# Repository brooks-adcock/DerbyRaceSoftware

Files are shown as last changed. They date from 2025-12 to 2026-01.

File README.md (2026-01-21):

# Pinewood Derby Race Software

Complete race management system for Pinewood Derby events, featuring automatic timing hardware and a modern web UI.

## Architecture Overview

```
┌─────────────────────────────────────────────────────────────────────┐
│                           WEB UI (Next.js)                          │
│              Race management, registration, results display         │
│                         http://localhost:3000                       │
└─────────────────────────────────────────────────────────────────────┘
                                    │
                                    │ HTTP + WebSocket
                                    ▼
┌─────────────────────────────────────────────────────────────────────┐
│                    TRACK CONTROLLER (Raspberry Pi)                  │
│           FastAPI server for gate control + finish sensors          │
│                   http://track-controller.local:8000                │
└─────────────────────────────────────────────────────────────────────┘
                                    │
                         GPIO / I2C │
                                    ▼
┌─────────────────────────────────────────────────────────────────────┐
│                          PHYSICAL HARDWARE                          │
│         Gate servo (PCA9685) + IR break-beam sensors (x4)           │
└─────────────────────────────────────────────────────────────────────┘
```

## Components

| Directory | Description |
|---|---|
| `ui_web/` | Next.js web application for race management |
| `pi/` | Raspberry Pi track controller (FastAPI + GPIO) |
| `mechanical/` | 3D printable parts (STL files) for track hardware |
| `notes/` | Development notes and troubleshooting logs |

---

## Quick Start

### 1. Development Environment (UI Only)

```bash
# Start the web UI (mock hardware mode)
./dev_start.sh

# View logs
./dev_tail.sh

# Stop services
./dev_stop.sh
```

Access at http://localhost:3000

### 2. Full System with Pi Hardware

See [pi/README.md](pi/README.md) for hardware setup instructions.

---

## Development Scripts

| Script | Description |
|---|---|
| `./dev_start.sh` | Start Docker services in background |
| `./dev_stop.sh` | Stop all Docker services |
| `./dev_build.sh` | Rebuild containers (fresh install) |
| `./dev_build.sh ui_web` | Rebuild specific service |
| `./dev_tail.sh` | Follow Docker logs |

---

## Web UI Pages

| Route | Purpose |
|---|---|
| `/` | Home / dashboard |
| `/register` | Car registration form |
| `/heats` | Heat management and race control |
| `/results` | Results leaderboard |
| `/public` | Spectator display (large screen) |
| `/admin` | System administration |
| `/health` | Hardware connection status |

---

## Track Controller API

The Raspberry Pi exposes a REST + WebSocket API:

| Endpoint | Method | Description |
|---|---|---|
| `/health` | GET | Health check, track count, gate status |
| `/gate` | GET/POST | Gate position control |
| `/servo/calibration` | GET/POST | Servo angle calibration |
| `/servo/test` | POST | Test servo at specific angle |
| `/race/run` | POST | Start a heat (drops gate, monitors sensors) |
| `/history` | GET | Past heat results |
| `/ws/results` | WS | Real-time race results stream |
| `/ws/status` | WS | Live hardware status (20Hz) |

Full API documentation: [pi/README.md](pi/README.md)

---

## Hardware Components

| Component | Purpose |
|---|---|
| Raspberry Pi 4B | Track controller |
| PCA9685 PWM Driver | Servo control via I2C |
| Hitec HS-5625MG Servo | Gate mechanism |
| DFRobot SEN0503 (x4) | Finish line IR sensors |

Detailed wiring and setup: [pi/HARDWARE.md](pi/HARDWARE.md)

---

## Tech Stack

- **Frontend:** Next.js 14, React, Tailwind CSS, Headless UI
- **Backend:** FastAPI (Python), Docker
- **Hardware:** Raspberry Pi OS, pigpio, adafruit-circuitpython-pca9685
- **Communication:** REST API, WebSockets, mDNS/Zeroconf

---

## Project Structure

```
RaceSoftware/
├── ui_web/
│   ├── code/              # Next.js application source
│   │   ├── src/app/       # Pages and API routes
│   │   ├── src/components/# React components
│   │   └── src/lib/       # Utilities and storage
│   ├── Dockerfile.dev     # Development container
│   └── start.sh           # Container entrypoint
├── pi/
│   ├── code/              # FastAPI application
│   │   ├── main.py        # API endpoints
│   │   ├── hardware.py    # GPIO/servo control
│   │   ├── models.py      # Pydantic schemas
│   │   └── storage.py     # Result persistence
│   ├── setup/             # SD card prep scripts
│   ├── HARDWARE.md        # Wiring diagrams
│   └── README.md          # Pi setup guide
├── mechanical/            # 3D printable parts (.stl)
├── docker-compose.dev.yml # Development stack
└── dev_*.sh               # Helper scripts
```

---

## Race Day Workflow

1. **Setup:** Connect Pi to venue WiFi, verify `/health` endpoint
2. **Registration:** Enter cars via `/register` page
3. **Generate Heats:** System creates balanced heat schedule
4. **Race:** Call cars to lanes, click "Start Race" on `/heats`
5. **Results:** Live times appear on `/public` display
6. **Finals:** Top cars race for placement

---

## Troubleshooting

**Can't connect to Pi:**
- Check Pi is on same network as your computer
- Try `ping track-controller.local`
- macOS Sequoia requires "Local Network" permission for Terminal

**Gate doesn't move:**
- Verify PCA9685 detected: `sudo i2cdetect -y 1`
- Check servo power supply (separate 5V, not from Pi)
- Test calibration: `curl -X POST .../servo/test -d '{"angle": 45}'`

**Sensors not triggering:**
- Realign IR emitter/receiver pairs
- Check 3.3V power to sensors
- Shield from ambient IR (sunlight, fluorescent lights)

See [notes/connection_mystery.md](notes/connection_mystery.md) for detailed network debugging.

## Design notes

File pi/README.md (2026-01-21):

# Pinewood Derby Track Controller (Raspberry Pi)

Headless Raspberry Pi API for controlling the race gate, reading finish sensors, and reporting heat results.

## Recommended Hardware

- **Raspberry Pi 4B** (2GB+ RAM) or **Pi Zero 2 W** for compact installs
- **High-endurance SD card** (Samsung PRO Endurance 32GB recommended)
- Servo motor for gate control
- Finish line sensors (IR break-beam or laser)

---

## Quick Start (One Command Setup)

### Prerequisites

1. Download **Raspberry Pi OS Lite (64-bit)** from:
   https://www.raspberrypi.com/software/operating-systems/

2. Place the image (`.img` or `.img.xz`) in the `pi/os/` directory
   - Keep the original filename (e.g., `2025-12-04-raspios-trixie-arm64-lite.img.xz`)

3. Create your configuration file:
   ```bash
   cd pi
   cp env.template .env
   # Edit .env with your WiFi credentials
   ```

### Flash & Configure SD Card

```bash
cd pi/setup
chmod +x prepare_sd.sh
./prepare_sd.sh
```

The script will:
- Prompt you to insert the SD card
- Scan and list available disks for you to choose
- Flash the OS image
- Enable SSH
- Configure **both** WiFi networks (dev + venue)
- Set up the `pi` user
- Copy all track controller code
- Configure auto-setup on first boot

### Boot the Pi

1. Insert SD card into Raspberry Pi
2. Connect power
3. Wait ~3-5 minutes for first boot setup
4. Verify: `curl http://track-controller.local:8000/health`

---

## API Endpoints

| Method | Endpoint | Description |
|---|---|---|
| GET | `/health` | Health check, returns track count and gate status |
| GET | `/gate` | Get current gate position |
| POST | `/gate` | Set gate up/down (`{"is_down": true}`) |
| GET | `/servo/calibration` | Get current servo angle calibration |
| POST | `/servo/calibration` | Set servo angles (`{"up_angle": 90, "down_angle": 0}`) |
| POST | `/servo/test` | Test servo at specific angle (`{"angle": 45}`) |
| POST | `/race/run` | Start a heat (`{"heat_id": "...", "occupied_lanes": [1,2,3]}`) |
| GET | `/history` | Get past heat results (`?limit=100`) |
| GET | `/history/{heat_id}` | Get specific heat result |
| GET | `/history/last` | Get most recent heat result |
| WS | `/ws/results` | WebSocket for real-time race results |
| WS | `/ws/status` | WebSocket for live hardware status (20Hz) |

### WebSocket: `/ws/results`

Subscribe to race results as they complete:

```javascript
const ws = new WebSocket('ws://track-controller.local:8000/ws/results');
ws.onmessage = (event) => {
  const msg = JSON.parse(event.data);
  if (msg.type === 'race_result') {
    console.log('Race finished:', msg.data);
  }
};
// Ping to keep alive
ws.send(JSON.stringify({ type: 'ping' }));
```

### WebSocket: `/ws/status`

Stream live hardware state (sensor triggers, servo angle):

```javascript
const ws = new WebSocket('ws://track-controller.local:8000/ws/status');
ws.onmessage = (event) => {
  const msg = JSON.parse(event.data);
  if (msg.type === 'hardware_status') {
    // { sensors: [true, true, false, true], servo_angle: 90, ... }
  }
};
// Pause/resume streaming
ws.send(JSON.stringify({ type: 'stop' }));
ws.send(JSON.stringify({ type: 'start' }));
```

### Example: Run a Race

```bash
curl -X POST http://track-controller.local:8000/race/run \
  -H "Content-Type: application/json" \
  -d '{"heat_id": "heat-001", "occupied_lanes": [1, 2, 3, 4]}'
```

Response:
```json
{
  "heat_id": "heat-001",
  "started_at": "2024-01-15T10:30:00",
  "finished_at": "2024-01-15T10:30:04",
  "lane_results": [
    {"lane_number": 1, "finish_time_ms": 2847.32, "place": 1, "is_dnf": false},
    {"lane_number": 2, "finish_time_ms": 3102.45, "place": 2, "is_dnf": false},
    {"lane_number": 3, "finish_time_ms": 3256.78, "place": 3, "is_dnf": false},
    {"lane_number": 4, "finish_time_ms": 3401.12, "place": 4, "is_dnf": false}
  ],
  "is_complete": true
}
```

---

## Local Development (Mock Mode)

For UI development without a physical Pi:

```bash
cd pi
docker build -f Dockerfile.dev -t track-api-dev .
docker run -p 8000:8000 track-api-dev
```

Or without Docker:

```bash
cd pi/code
export MOCK_HARDWARE=1
export NUM_TRACKS=4
pip install -r ../requirements.txt
uvicorn main:app --reload --port 8000
```

Mock mode simulates races with random finish times (2.5-4.5 seconds).

---

## Stability Features

| Feature | Implementation |
|---|---|
| Auto-restart on crash | systemd `Restart=always` with 3s delay |
| Network discovery | Zeroconf/mDNS (`track-controller.local`) |
| Result persistence | JSON file (last 1000 heats) |
| State recovery | `GET /history/{heat_id}` to re-fetch results |
| Selective sensing | Only waits for `occupied_lanes` sensors |
| Atomic writes | Temp file + rename for crash safety |

---

## Hardware Configuration

GPIO pins are configurable via environment variables in the systemd service:

| Variable | Default | Description |
|---|---|---|
| `NUM_TRACKS` | 4 | Number of lanes |
| `SERVO_PIN` | 18 | GPIO pin for gate servo |
| `SENSOR_PIN_1` | 17 | GPIO pin for lane 1 sensor |
| `SENSOR_PIN_2` | 27 | GPIO pin for lane 2 sensor |
| `SENSOR_PIN_3` | 22 | GPIO pin for lane 3 sensor |
| `SENSOR_PIN_4` | 23 | GPIO pin for lane 4 sensor |

Edit `/etc/systemd/system/track-api.service` to change these.

---

## Troubleshooting

**Can't find Pi on network:**
```bash
# Try direct IP scan
nmap -sn 192.168.1.0/24 | grep -i raspberry

# Or check your router's DHCP client list
```

**Service not running:**
```bash
ssh pi@track-controller.local
sudo systemctl status track-api
sudo journalctl -u track-api -f
```

**Restart the service:**
```bash
sudo systemctl restart track-api
```

**Check setup logs (first boot):**
```bash
cat /var/log/track-api-setup.log
```

---

## File Structure

```
pi/
├── os/
│   └── *.img[.xz]          # Raspberry Pi OS image (you provide)
├── code/
│   ├── main.py             # FastAPI application
│   ├── models.py           # Pydantic schemas
│   ├── hardware.py         # GPIO/Mock hardware interface
│   ├── storage.py          # JSON file history
│   └── discovery.py        # Zeroconf/mDNS
├── setup/
│   ├── prepare_sd.sh       # Interactive SD card setup
│   ├── track-api.service   # systemd unit file
│   └── first_boot.sh       # Manual setup (alternative)
├── env.template            # WiFi config template
├── .env                    # Your WiFi config (git-ignored)
├── Dockerfile.dev          # Local development container
├── requirements.txt        # Python dependencies
└── README.md               # This file
```

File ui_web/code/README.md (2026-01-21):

# Pinewood Derby Web UI

Next.js web application for managing Pinewood Derby races. Built with Tailwind CSS and Radiant components.

## Development

### With Docker (Recommended)

From the project root:

```bash
./dev_start.sh      # Start services
./dev_tail.sh       # View logs
./dev_stop.sh       # Stop services
```

Access at http://localhost:3000

### Without Docker

```bash
cd ui_web/code
npm install
npm run dev
```

---

## Pages

| Route | Purpose | Access |
|---|---|---|
| `/` | Dashboard / home | All |
| `/register` | Car registration form | Admin |
| `/heats` | Heat management, race control | Admin |
| `/results` | Results leaderboard | All |
| `/public` | Spectator display (TV/projector) | All |
| `/admin` | System settings | Admin |
| `/health` | Hardware connection status | Admin |
| `/judging` | Design judging interface | Judges |
| `/setup` | Initial system setup | Admin |

---

## API Routes

| Endpoint | Description |
|---|---|
| `/api/cars` | CRUD for registered cars |
| `/api/race` | Race/heat management, proxies to Pi |
| `/api/hardware` | Hardware status from Pi |
| `/api/settings` | System configuration |

---

## Key Components

Located in `src/components/`:

| Component | Purpose |
|---|---|
| `countdown-overlay.tsx` | Race start countdown |
| `setup-checklist.tsx` | Pre-race setup verification |
| `navigation-wrapper.tsx` | Responsive nav with drawer |
| `menu-drawer.tsx` | Mobile navigation |

### UI Library (Radiant)

Pre-built components from `src/components/`:
- `button.tsx` - Primary/secondary/outline buttons
- `text.tsx` - Heading, Subheading, Lead typography
- `container.tsx` - Max-width wrapper
- `navbar.tsx`, `footer.tsx` - Layout components

---

## Data Storage

Race data persists in `data/` directory:

| File | Contents |
|---|---|
| `cars.json` | Registered cars |
| `settings.json` | System configuration |

---

## Environment Variables

| Variable | Description | Default |
|---|---|---|
| `NEXT_PUBLIC_HOST_IP` | Pi's IP for API calls | `localhost` |
| `WATCHPACK_POLLING` | Enable hot-reload in Docker | `true` |

---

## Hardware Communication

The UI connects to the Raspberry Pi track controller:

```typescript
// src/lib/usePiWebSocket.ts
// WebSocket hook for real-time race results

// src/lib/storage.ts  
// Data persistence and Pi API proxy
```

When Pi is unavailable, the UI operates in standalone mode with manual time entry.

---

## Tech Stack

- **Framework:** Next.js 14 (App Router)
- **Styling:** Tailwind CSS
- **Components:** Headless UI, Heroicons
- **Animations:** Framer Motion

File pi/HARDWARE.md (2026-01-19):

# Pinewood Derby Track Controller - Hardware Setup

## Components

### 1. Servo Controller: PCA9685 16-Channel PWM Driver
**Amazon B07H9ZTWNC**

| Spec | Value |
|---|---|
| Channels | 16 PWM outputs |
| Interface | I2C (address 0x40 default) |
| PWM Resolution | 12-bit (4096 steps) |
| PWM Frequency | 24-1526 Hz (50Hz for servos) |
| Operating Voltage | 3.3V or 5V logic |
| Servo Power | Separate V+ terminal (5-6V for servos) |

**Why this board:** Offloads PWM generation from the Pi's CPU, provides clean servo signals, and frees up GPIO pins for sensors.

#### Wiring to Raspberry Pi

| PCA9685 Pin | Pi Pin | GPIO |
|---|---|---|
| VCC | Pin 1 | 3.3V |
| GND | Pin 6 | Ground |
| SDA | Pin 3 | GPIO 2 (SDA1) |
| SCL | Pin 5 | GPIO 3 (SCL1) |
| V+ | **External 5-6V** | Servo power (NOT from Pi) |

⚠️ **Important:** Use an external 5V power supply for V+ (servo power). Do NOT power servos from the Pi's 5V pin—it can't supply enough current and may brown out the Pi.

---

### 2. Gate Servo: Hitec HS-5625MG
**Digital high-torque metal gear servo**

| Spec | Value |
|---|---|
| Type | Digital, metal gears |
| Torque | 110 oz-in (7.9 kg-cm) @ 4.8V, 131 oz-in (9.4 kg-cm) @ 6.0V |
| Speed | 0.17 sec/60° @ 4.8V, 0.14 sec/60° @ 6.0V |
| Voltage | 4.8V - 6.0V |
| Pulse Width | 900µs - 2100µs |
| Neutral | 1500µs |
| Deadband | ~4µs |

**Why this servo:** High torque, metal gears for durability, digital precision with tiny deadband.

#### Wiring to PCA9685

| Servo Wire | PCA9685 Terminal |
|---|---|
| Brown (GND) | GND row |
| Red (V+) | V+ row |
| Yellow (Signal) | **Channel 0** PWM |

#### Gate Positions (Calibrate via API)

The actual angles depend on your track geometry. Use the API to calibrate:

| Position | Default | Description |
|---|---|---|
| **UP** (holding) | 90° | Cars held at start |
| **DOWN** (released) | 0° | Gate drops, cars roll |

**Calibration API:**
```bash
# Test a specific angle
curl -X POST http://track-controller.local:8000/servo/test \
  -H "Content-Type: application/json" \
  -d '{"angle": 45}'

# Once you find the right angles, save them:
curl -X POST http://track-controller.local:8000/servo/calibration \
  -H "Content-Type: application/json" \
  -d '{"up_angle": 85, "down_angle": 15}'

# Check current calibration
curl http://track-controller.local:8000/servo/calibration
```

**Race Sequence:**
1. Gate starts in **UP** position (servo at calibrated up_angle)
2. On "GO" command, gate moves to **DOWN** position (calibrated down_angle)
3. **START TIME is recorded** when gate drops
4. Cars race down track...

---

### 3. Finish Line Sensors: DFRobot SEN0503 (x4)
**Mouser 426-SEN0503**

| Spec | Value |
|---|---|
| Type | Infrared break-beam (through-beam) |
| Detection Range | 50cm max |
| Response Time | < 2ms |
| Operating Voltage | 3.3V - 5V |
| Output | Digital (HIGH = beam intact, LOW = beam broken) |
| Output Type | NPN open-collector |

**Why these sensors:** Fast response time (~2ms), 3.3V compatible, perfect for detecting fast-moving pinewood derby cars.

#### Wiring to Raspberry Pi

Each SEN0503 has 3 wires:

| Wire Color | Connection |
|---|---|
| Red | 3.3V (Pi Pin 1 or 17) |
| Black | GND (Pi Pin 6, 9, 14, 20, 25, 30, 34, 39) |
| Yellow/Signal | GPIO (see below) |

#### GPIO Pin Assignments

| Lane | GPIO Pin | Pi Pin | Wire Color Suggestion |
|---|---|---|---|
| Lane 1 | GPIO 17 | Pin 11 | White |
| Lane 2 | GPIO 27 | Pin 13 | Blue |
| Lane 3 | GPIO 22 | Pin 15 | Green |
| Lane 4 | GPIO 23 | Pin 16 | Yellow |

⚠️ **Pull-ups Required:** Enable internal pull-ups on each GPIO pin. The SEN0503 output goes LOW when the beam is broken.

---

## Complete Wiring Diagram

```
                    RASPBERRY PI 4/5
                    ┌─────────────────────────────────────┐
                    │  Pin 1 (3.3V) ──────┬──── PCA9685 VCC
                    │  Pin 2 (5V)         │     (also powers sensors)
                    │  Pin 3 (GPIO2/SDA) ─┼──── PCA9685 SDA
                    │  Pin 4 (5V)         │
                    │  Pin 5 (GPIO3/SCL) ─┼──── PCA9685 SCL
                    │  Pin 6 (GND) ───────┼──── PCA9685 GND
                    │  ...                │     (common ground)
                    │  Pin 11 (GPIO17) ───┼──── Lane 1 Sensor
                    │  Pin 13 (GPIO27) ───┼──── Lane 2 Sensor
                    │  Pin 15 (GPIO22) ───┼──── Lane 3 Sensor
                    │  Pin 16 (GPIO23) ───┼──── Lane 4 Sensor
                    │  ...                │
                    └─────────────────────────────────────┘

                    PCA9685 SERVO DRIVER
                    ┌─────────────────────────────────────┐
                    │  V+ ←── External 5V Power Supply    │
                    │  GND ←── Common Ground              │
                    │                                     │
                    │  Channel 0 ──── HS-422 Servo        │
                    │    (PWM)        (Yellow wire)       │
                    └─────────────────────────────────────┘

                    EXTERNAL POWER
                    ┌─────────────────────────────────────┐
                    │  5V 2A DC Adapter                   │
                    │    └── V+ to PCA9685 V+ terminal    │
                    │    └── GND to common ground         │
                    └─────────────────────────────────────┘
```

---

## Power Requirements

| Component | Voltage | Current (max) |
|---|---|---|
| Raspberry Pi 4/5 | 5V USB-C | 3A |
| PCA9685 Logic | 3.3V (from Pi) | 10mA |
| HS-422 Servo | 5-6V (external) | 500mA peak |
| SEN0503 Sensors (x4) | 3.3V | 20mA each |

**Recommended Power Setup:**
- Pi: Official 5V/3A USB-C power supply
- Servo: Separate 5V/2A DC adapter to PCA9685 V+ terminal
- Sensors: Powered from Pi's 3.3V rail (plenty of headroom)

---

## Race Timing Sequence

```
TIME ─────────────────────────────────────────────────────────►

1. READY STATE
   Gate: UP (90°)
   Sensors: Monitoring (all HIGH)

2. "GO" COMMAND RECEIVED
   ├── Gate: Move to DOWN (0°)
   └── START_TIME = time.monotonic_ns()  ◄── TIMING STARTS HERE

3. CARS RACING
   Gate: DOWN
   Sensors: Waiting for triggers...

4. CAR CROSSES FINISH LINE
   Sensor goes LOW (beam broken)
   └── FINISH_TIME[lane] = time.monotonic_ns()
   └── ELAPSED_MS = (FINISH_TIME - START_TIME) / 1_000_000

5. ALL CARS FINISHED (or timeout)
   Gate: Return to UP
   └── Results saved & broadcast
```

---

## Software Configuration

The GPIO pins and servo settings are configured in the systemd service file and can be overridden:

```bash
# /etc/systemd/system/track-api.service
Environment="NUM_TRACKS=4"
Environment="SERVO_CHANNEL=0"
Environment="SERVO_UP_ANGLE=90"
Environment="SERVO_DOWN_ANGLE=0"
Environment="SENSOR_PIN_1=17"
Environment="SENSOR_PIN_2=27"
Environment="SENSOR_PIN_3=22"
Environment="SENSOR_PIN_4=23"
```

---

## Testing Checklist

### Before First Race

- [ ] PCA9685 detected: `sudo i2cdetect -y 1` (should show 0x40)
- [ ] Servo moves smoothly between UP and DOWN positions
- [ ] All 4 sensors trigger when beam is broken (test with finger)
- [ ] API health check returns correct track count
- [ ] WebSocket connection stable

### Test Commands

```bash
# Check I2C devices
sudo i2cdetect -y 1

# Test gate via API
curl -X POST http://track-controller.local:8000/gate \
  -H "Content-Type: application/json" \
  -d '{"is_down": true}'

# Run a test heat
curl -X POST http://track-controller.local:8000/race/run \
  -H "Content-Type: application/json" \
  -d '{"heat_id": "test-001", "occupied_lanes": [1, 2, 3, 4]}'
```

---

## Troubleshooting

| Issue | Likely Cause | Fix |
|---|---|-----|
| Servo jitters/buzzes | Insufficient power | Use dedicated 5V supply for V+ |
| Servo doesn't move | I2C not enabled | Run `sudo raspi-config` → Interface → I2C |
| Sensors always LOW | Misaligned beam | Realign emitter/receiver pair |
| Sensors always HIGH | Wiring issue | Check 3.3V, GND, and signal connections |
| Erratic timing | Ambient IR interference | Shield sensors from sunlight/fluorescent lights |
| I2C errors | Bad connection | Check SDA/SCL wiring, try shorter cables |

---

## Parts List Summary

| Qty | Item | Source | Notes |
|-----|---|---|---|
| 1 | Raspberry Pi 4B (2GB+) | — | Or Pi 5 |
| 1 | PCA9685 16-Ch PWM Driver | Amazon B07H9ZTWNC | I2C servo controller |
| 1 | Hitec HS-5625MG Servo | — | Gate mechanism (digital, metal gear) |
| 4 | DFRobot SEN0503 Sensors | Mouser 426-SEN0503 | Finish line |
| 1 | 5V 2A DC Adapter | — | Servo power |
| 1 | 5V 3A USB-C Adapter | — | Pi power |
| 1 | 32GB microSD (High Endurance) | — | Samsung PRO Endurance |
| — | Jumper wires, connectors | — | For wiring |

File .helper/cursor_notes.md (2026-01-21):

# Cursor Notes (Memories)

These are the AI memories/notes that persist across all projects.

---

## This Project: Pinewood Derby Race Software

A complete race management system with:
- **Web UI** (`ui_web/`) - Next.js app for race management, registration, results
- **Track Controller** (`pi/`) - Raspberry Pi FastAPI server for gate + sensors
- **Mechanical** (`mechanical/`) - 3D printable parts for track hardware

The Pi connects to the web UI via REST + WebSocket. In dev mode, the Pi runs in mock hardware mode with simulated race times.

---

## Project Structure

**Docker Service Directory Layout**
For Docker services, organize directories with container meta files (Dockerfile, start.sh, scripts) at the service root (e.g., `./ui_web/`) and the actual application code in a `./code` subdirectory (e.g., `./ui_web/code/`). The Docker context should be the service root, not the code directory.

**Separate Script Files**
Create separate script files (e.g., `start.sh`) in the codebase instead of embedding code within Dockerfiles.

---

## Tech Stack Preferences

**Docker Compose Syntax**
Use `docker compose` (plugin syntax) instead of `docker-compose` (standalone). Colima provides the docker compose plugin.

**Web Framework**
Tornado is the preferred Python web framework.

---

## UI Components (Template Project)

**Use Radiant Tailwind Components**
When building UI in this project, prefer using the pre-built Radiant (Tailwind Plus) components from `ui_web/code/src/components/`. Available components include: Button (primary/secondary/outline), Heading, Subheading, Lead, Container, Navbar, Footer, BentoCard, Testimonials, LogoCloud, LogoCluster, LogoTimeline, AnimatedNumber, Gradient, Screenshot, Map, PlusGrid, LinkedAvatars, and Link. Also leverage @headlessui/react for modals/dropdowns/tabs, @heroicons/react for icons, and framer-motion for animations.

---

## Code Style

- Variables: `snake_case`
- Constants: `UPPER_CASE`
- Functions: `camelCase`
- Classes: `PascalCase`
- Factory methods: `MakeObjectFromParameters`
- Arrays: plural names
- Booleans: prefix with `is_`

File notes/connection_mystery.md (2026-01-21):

# SSH Connection Mystery

## Resolution (Jan 19, 2026)

**Root Cause:** macOS Sequoia 15+ requires explicit "Local Network" permission for apps to access LAN devices.

**Fix:** System Settings → Privacy & Security → Local Network → Enable for Terminal.app (or iTerm, etc.)

This was a multi-hour debugging session that ruled out every traditional network issue before discovering macOS's new permission model.

---

## Basic Facts

| Item | Value |
|---|---|
| Mac IP | 192.168.1.19 |
| Pi IP | 192.168.1.106 |
| Pi MAC | d8:3a:dd:f8:73:c6 |
| Subnet | 192.168.1.x/24 |
| Gateway | 192.168.1.1 |
| Pi Hostname | track-controller |
| Router | Netgear Nighthawk |
| Upstream | Google Fiber router (bridge mode) |
| WiFi SSID | Shoccoree 2.4GHz (both Mac and Pi confirmed on same SSID) |

## What Works ✅

- Pi can ping Mac (192.168.1.19) - always works
- Mac ARP table has entry for Pi
- Traceroute from Mac to Pi works (UDP): `traceroute -n 192.168.1.106` → 1 hop, ~5ms
- SSH daemon running on Pi: `systemctl status ssh` → active
- SSH listening on all interfaces: `ss -tlnp` → `0.0.0.0:22`
- Pi network interface up: `ip link show wlan0` → UP
- No firewall rules blocking: `nft list ruleset` and `iptables -L` → empty

## What Fails ❌

- Mac cannot ping Pi: `ping 192.168.1.106` → "No route to host"
- Mac cannot SSH to Pi: `ssh pi@192.168.1.106` → "No route to host"  
- Hostname resolution: `ping track-controller.local` → "Unknown host"

## Debug Steps Taken

1. **Verified SSH running on Pi**
   ```bash
   sudo systemctl status ssh  # → active (running)
   ```

2. **Verified network interface up**
   ```bash
   ip link show wlan0  # → UP
   ```

3. **Confirmed bidirectional awareness**
   - Pi can ping Mac ✅
   - Mac has ARP entry for Pi ✅

4. **Verbose SSH attempt**
   ```bash
   ssh -v -o ConnectTimeout=5 pi@192.168.1.106
   # debug1: Connecting to 192.168.1.106 port 22
   # debug1: connect to address 192.168.1.106 port 22: No route to host
   ```

5. **Checked Pi firewall**
   ```bash
   sudo nft list ruleset   # → empty
   sudo iptables -L -n     # → empty (ACCEPT all)
   ```

6. **Traceroute test (UDP)**
   ```bash
   traceroute -n 192.168.1.106
   # 1  192.168.1.106  7.745 ms  4.290 ms  2.867 ms
   ```
   UDP packets reach the Pi!

7. **Verified SSH bind address**
   ```bash
   sudo ss -tlnp | grep 22
   # LISTEN 0 128 0.0.0.0:22 0.0.0.0:* users:(("sshd",pid=110,fd=6))
   ```

8. **Tried disabling WiFi power management**
   ```bash
   sudo iw wlan0 set power_save off
   ```

## The Mystery

- **UDP works** (traceroute reaches Pi)
- **TCP fails** (ping ICMP and SSH TCP both fail with "No route to host")
- **One-way communication**: Pi → Mac works, Mac → Pi fails
- ARP entry exists on Mac, so Layer 2 should be fine

## Hypotheses (Researched)

### 🔴 HIGH LIKELIHOOD

#### 1. WiFi AP/Client Isolation (Router Setting)
Many routers have "AP Isolation", "Client Isolation", or "Guest Network" features that **block WiFi clients from talking to each other**. This perfectly explains:
- Pi can initiate outbound (allowed)
- Mac cannot initiate to Pi (blocked by AP)
- UDP traceroute might work (some routers only block TCP)

**How to test:**
- Check router admin page for "AP Isolation", "Client Isolation", "Wireless Isolation"
- Try connecting Mac to same SSID as Pi (if on different SSIDs)
- Try connecting Pi via ethernet temporarily

#### 2. firewalld Running on Pi (Trixie Default?)
Raspberry Pi OS Trixie uses NetworkManager and **may have firewalld enabled by default**. Even if `nft list ruleset` is empty, firewalld manages its own zones.

**How to test on Pi:**
```bash
sudo systemctl status firewalld
sudo firewall-cmd --list-all
sudo firewall-cmd --zone=public --list-services
```

**Quick fix:**
```bash
sudo systemctl stop firewalld
sudo systemctl disable firewalld
```

#### 3. nftables Default Chain Policy
Even with empty rules, nftables can have a **default DROP policy** on input chains. Our setup script does `nft flush ruleset` but doesn't set ACCEPT policy.

**How to test on Pi:**
```bash
sudo nft list chain inet filter input 2>/dev/null
# If this shows policy=drop, that's the problem
```

**Quick fix:**
```bash
sudo nft add table inet filter
sudo nft add chain inet filter input { type filter hook input priority 0 \; policy accept \; }
```

### 🟡 MEDIUM LIKELIHOOD

#### 4. Reverse Path Filtering (rp_filter)
Linux kernel's `rp_filter` can drop packets if the return path doesn't match the incoming interface. WiFi's asymmetric routing might trigger this.

**How to test on Pi:**
```bash
cat /proc/sys/net/ipv4/conf/wlan0/rp_filter
# If 1 or 2, try disabling:
sudo sysctl -w net.ipv4.conf.wlan0.rp_filter=0
sudo sysctl -w net.ipv4.conf.all.rp_filter=0
```

#### 5. DHCP/IP Conflict
If the Pi previously had a different IP or was on ethernet, the router might have stale ARP/DHCP entries causing routing confusion.

**How to test:**
- Check router's DHCP client list for duplicate entries
- On Pi: `ip addr show` - verify only one IP on wlan0
- On Mac: `arp -d 192.168.1.106` then retry

#### 6. WiFi Power Management / Driver Bug
Pi's WiFi chip (Broadcom) has known power-saving issues. Incoming connections can be dropped when the interface is sleeping.

**How to test on Pi:**
```bash
sudo iw wlan0 get power_save  # Check current state
sudo iw wlan0 set power_save off  # Disable
iwconfig wlan0  # Check "Power Management"
```

**Permanent fix** - add to `/etc/rc.local`:
```bash
iw wlan0 set power_save off
```

### ✅ RULED OUT (Mac-Side)

#### Mac VPN Interference
Checked - 4 utun interfaces exist but only have IPv6 addresses. IPv4 routing table correctly routes 192.168.1.x via en0.
```bash
route get 192.168.1.106  # → interface: en0 ✅
```

#### Mac Firewall
Checked - Mac firewall is disabled.
```bash
/usr/libexec/ApplicationFirewall/socketfilterfw --getglobalstate
# → Firewall is disabled ✅
```

#### Mac Routing
Verified - default route and 192.168.1.x subnet both go via en0 to gateway 192.168.1.1.

### 🟢 LOWER LIKELIHOOD

#### 7. SSH Config Restricting Connections
`/etc/ssh/sshd_config` might have `AllowUsers`, `AllowGroups`, or `Match` blocks restricting who can connect.

**How to test on Pi:**
```bash
grep -E "^(Allow|Deny|Match)" /etc/ssh/sshd_config
```

#### 8. Subnet Mask Mismatch
If Pi has wrong netmask (e.g., /25 instead of /24), it might think Mac is on a different network.

**How to test on Pi:**
```bash
ip addr show wlan0 | grep inet
# Should show: inet 192.168.1.106/24
```

### Our Setup Context

From `prepare_sd.sh`, the first-boot script:
- Uses NetworkManager (Trixie)
- Runs `nft flush ruleset` (but doesn't set policy)
- Doesn't check/disable firewalld
- Doesn't disable rp_filter
- Doesn't disable WiFi power management persistently

## Recommended Fix Order

1. **Check firewalld**: `sudo systemctl status firewalld` - if running, stop it
2. **Check AP isolation**: Look in router settings
3. **Disable rp_filter**: `sudo sysctl -w net.ipv4.conf.all.rp_filter=0`
4. **Disable WiFi power save**: `sudo iw wlan0 set power_save off`
5. **Try ethernet**: Bypass all WiFi issues

## Debug Session (Jan 19, 2026)

| Test | Result |
|---|---|
| firewalld | Not installed ✅ ruled out |
| rp_filter | Disabled (was 2) - still fails ✅ ruled out |
| WiFi power_save | Disabled (was on) - still fails ✅ ruled out |
| Netmask | /24 correct ✅ ruled out |
| SSH localhost | nc succeeded ✅ SSH daemon working |
| SSH own wlan0 IP | nc 192.168.1.106:22 succeeded ✅ |
| Ethernet test | Pi at .35 via cat5, Mac still "no route to host" ❌ |
| Mac ARP for Pi | **(incomplete)** - Pi not responding to ARP! |
| Static ARP bypass | Added static entry, still fails |
| tcpdump on Mac | **No packets captured** - packets not leaving Mac |
| Other Linux machine | Can ping Pi at .106 ✅ |
| Chromebook SSH to Pi | Works ✅ |
| Mac PF firewall | **ENABLED** with PIA VPN anchor rules |
| Removed PIA + reboot | Still fails ❌ |
| macOS version | **15.6.1 (Sequoia)** |

**ACTUAL ROOT CAUSE: macOS Sequoia Local Network Permission!**

Sequoia 15+ requires apps to have explicit "Local Network" permission to access LAN devices.

## Resolution Steps

1. Open **System Settings** on Mac
2. Navigate to **Privacy & Security → Local Network**
3. Enable access for **Terminal.app** (or your terminal emulator)
4. Restart Terminal and retry SSH

This permission was introduced in macOS Sequoia (15.0) and blocks apps from initiating connections to local network devices without explicit user consent.

## Lessons Learned

- "No route to host" on macOS can mean permission denied, not a routing issue
- UDP (traceroute) may work when TCP is blocked by app permissions
- Always check OS-level privacy permissions on modern macOS
- Other devices (Linux, Chromebook) working is a strong signal of Mac-specific issue

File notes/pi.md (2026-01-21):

# Raspberry Pi Notes

> **Keep Updated:** When learning new Pi-specific quirks, say "update pi notes" to add them here.

## OS Info
- Running: Raspberry Pi OS Trixie (Debian 13, 64-bit Lite)
- Uses NetworkManager (not wpa_supplicant)

## Keyboard Layout

`localectl list-keymaps` doesn't work on Pi OS Lite (no keymap files installed).

### Set Dvorak manually:
```bash
sudo sed -i 's/XKBLAYOUT=.*/XKBLAYOUT="us"/' /etc/default/keyboard
sudo sed -i 's/XKBVARIANT=.*/XKBVARIANT="dvorak"/' /etc/default/keyboard
sudo dpkg-reconfigure -f noninteractive keyboard-configuration
sudo setupcon --force
```

### Or via raspi-config:
Localisation Options → Keyboard → Generic 104-key → Other → English (US) → English (US, Dvorak)

## Servo Control (curl commands)

```bash
# Test servo at specific angle (0-180)
curl -X POST http://localhost:8000/servo/test -H "Content-Type: application/json" -d '{"angle": 45}'

# Get calibration
curl http://localhost:8000/servo/calibration

# Set calibration
curl -X POST http://localhost:8000/servo/calibration -H "Content-Type: application/json" -d '{"up_angle": 90, "down_angle": 0}'

# Control gate
curl -X POST http://localhost:8000/gate -H "Content-Type: application/json" -d '{"is_down": true}'
```

## Useful Debug Commands

```bash
# Service logs
sudo journalctl -u track-api -f

# Setup logs
cat /var/log/firstrun.log
cat /var/log/track-api-setup.log

# Check service status
sudo systemctl status track-api

# Restart service
sudo systemctl restart track-api
```

## Default Credentials
- User: `pi`
- Password: `pi`

## Network Discovery

```bash
# Find Pi on network via mDNS
ping track-controller.local

# Or scan network
nmap -sn 192.168.1.0/24 | grep -i raspberry

# Check mDNS registration
avahi-browse -art | grep track-controller
```

## I2C (Servo Controller)

```bash
# Verify PCA9685 is detected (should show 0x40)
sudo i2cdetect -y 1

# If not detected, enable I2C
sudo raspi-config  # Interface Options → I2C → Enable
```

## Race API Quick Reference

```bash
# Health check
curl http://track-controller.local:8000/health

# Start a race
curl -X POST http://track-controller.local:8000/race/run \
  -H "Content-Type: application/json" \
  -d '{"heat_id": "heat-001", "occupied_lanes": [1, 2, 3, 4]}'

# Get last result
curl http://track-controller.local:8000/history/last
```

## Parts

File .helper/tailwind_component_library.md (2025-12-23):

# Tailwind Component Library Inventory

## Template: Radiant (Tailwind Plus)

A premium SaaS marketing site template from [Tailwind Plus](https://tailwindcss.com/plus).

---

## Core Dependencies

| Package | Version | Purpose |
|---|---|---|
| `tailwindcss` | ^4.1.4 | Utility-first CSS framework |
| `@headlessui/react` | ^2.1.1 | Unstyled, accessible UI primitives |
| `@heroicons/react` | ^2.1.4 | Official Tailwind icon set |
| `framer-motion` | ^11.2.10 | Animation library |
| `clsx` | ^2.1.1 | Class name utility |
| `next` | 14.2.11 | React framework |

---

## Pre-Built Components

### Layout & Structure
| Component | File | Description |
|---|---|---|
| Container | `container.tsx` | Responsive max-width wrapper |
| Navbar | `navbar.tsx` | Site header with navigation |
| Footer | `footer.tsx` | Site footer with links |
| PlusGrid | `plus-grid.tsx` | Grid layout with decorative plus signs |

### Typography
| Component | File | Description |
|---|---|---|
| Heading | `text.tsx` | Large display headings (H1-H6) |
| Subheading | `text.tsx` | Mono-spaced uppercase labels |
| Lead | `text.tsx` | Large paragraph text |

### Interactive Elements
| Component | File | Variants |
|---|---|---|
| Button | `button.tsx` | `primary`, `secondary`, `outline` |
| Link | `link.tsx` | Enhanced Next.js Link wrapper |

### Marketing & Display
| Component | File | Description |
|---|---|---|
| BentoCard | `bento-card.tsx` | Feature cards in bento grid layout |
| Screenshot | `screenshot.tsx` | App screenshot with frame |
| Testimonials | `testimonials.tsx` | Customer quote carousel/grid |
| Map | `map.tsx` | Decorative world map with markers |

### Logo & Branding
| Component | File | Description |
|---|---|---|
| Logo | `logo.tsx` | Site logo component |
| LogoCloud | `logo-cloud.tsx` | Row of partner/client logos |
| LogoCluster | `logo-cluster.tsx` | Grouped logos (e.g., integrations) |
| LogoTimeline | `logo-timeline.tsx` | Animated logo timeline |

### Animation & Effects
| Component | File | Description |
|---|---|---|
| AnimatedNumber | `animated-number.tsx` | Counting number animation |
| Gradient | `gradient.tsx` | Decorative gradient backgrounds |
| Keyboard | `keyboard.tsx` | 3D keyboard illustration |
| LinkedAvatars | `linked-avatars.tsx` | Connected avatar display |

---

## Pre-Built Pages

| Route | File | Description |
|---|---|---|
| `/` | `page.tsx` | Marketing homepage |
| `/pricing` | `pricing/page.tsx` | Pricing tiers page |
| `/company` | `company/page.tsx` | About/Company page |
| `/login` | `login/page.tsx` | Login form page |
| `/blog` | `blog/page.tsx` | Blog listing |
| `/blog/[slug]` | `blog/[slug]/page.tsx` | Individual blog post |
| `/studio` | `studio/[[...tool]]/page.tsx` | Sanity CMS admin |

---

## Static Assets

### Images (`/public/`)
- **Company photos**: 5 images
- **Team photos**: 9 team member headshots
- **Testimonial photos**: 6 customer photos
- **Screenshots**: 5 app screenshots
- **Map markers**: 5 location images

### Logos (`/public/`)
- **Logo cloud**: 5 partner logos (Laravel, SavvyCal, Statamic, Transistor, Tuple)
- **Logo cluster**: 6 job board logos
- **Logo timeline**: 12 integration logos (Slack, Zoom, Asana, etc.)
- **Investors**: 2 investor logos

---

## Headless UI Components Available

Via `@headlessui/react`, the following unstyled primitives are available:
- Dialog (Modal)
- Disclosure (Accordion)
- Listbox (Select)
- Menu (Dropdown)
- Popover
- RadioGroup
- Switch (Toggle)
- Tabs
- Transition

---

## Heroicons Available

Via `@heroicons/react`, 300+ icons in three styles:
- `@heroicons/react/24/outline` - 24px outlined
- `@heroicons/react/24/solid` - 24px filled
- `@heroicons/react/20/solid` - 20px filled (for smaller UI)
- `@heroicons/react/16/solid` - 16px filled (for inline)

Browse all icons: https://heroicons.com

---

## Notes

- Uses **Tailwind CSS v4** (new CSS-first config)
- Blog powered by **Sanity CMS**
- All components use `clsx` for conditional class merging
- Follows Headless UI data-attribute patterns (`data-hover`, `data-disabled`)

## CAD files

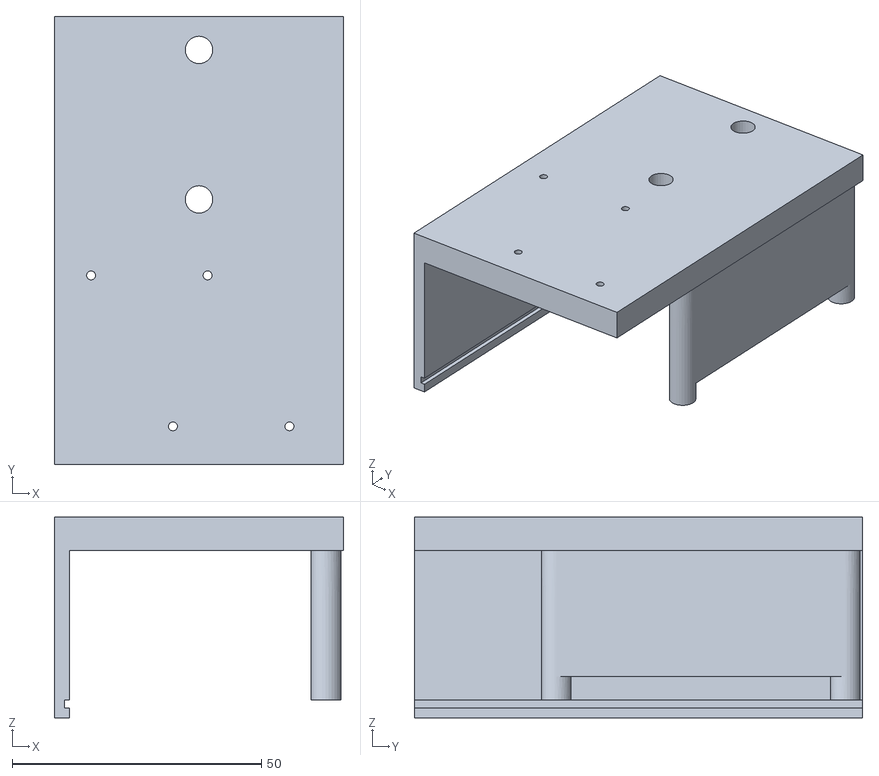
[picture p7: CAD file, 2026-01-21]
mechanical/PiMount.stl
58.0 x 90.0 x 40.2

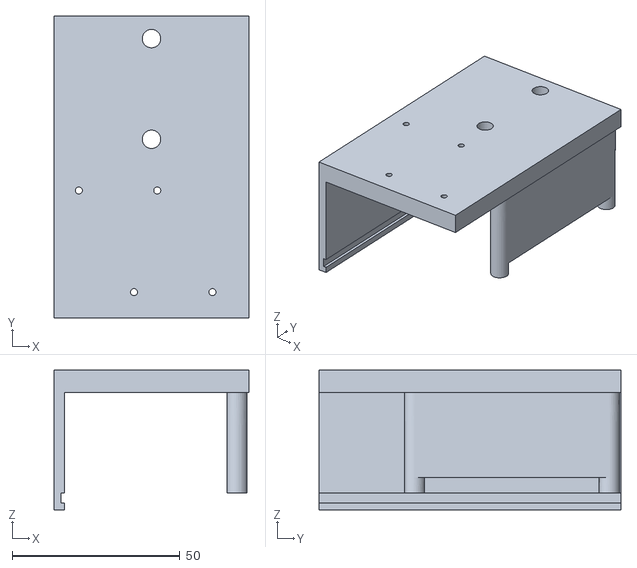
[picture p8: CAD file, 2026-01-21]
mechanical/PiMount_v2.stl
58.0 x 90.0 x 41.7

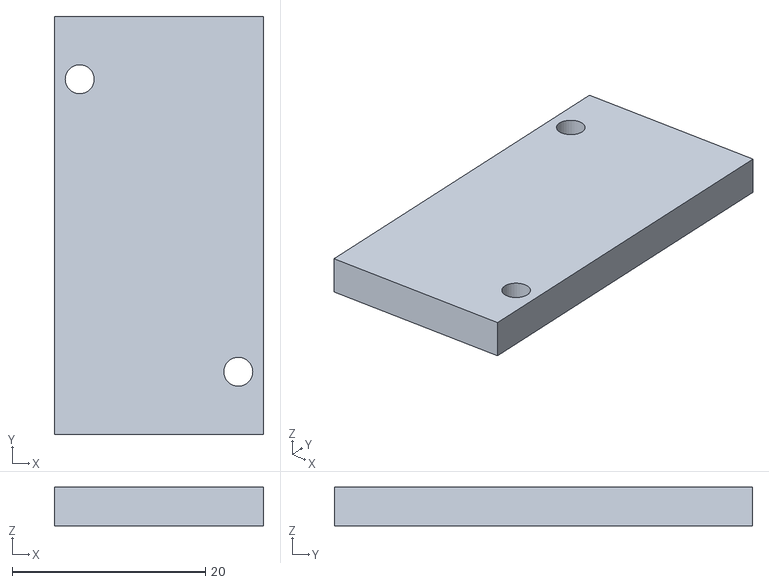
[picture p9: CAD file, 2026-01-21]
mechanical/PowerSpacer.stl
21.6 x 43.3 x 4.00

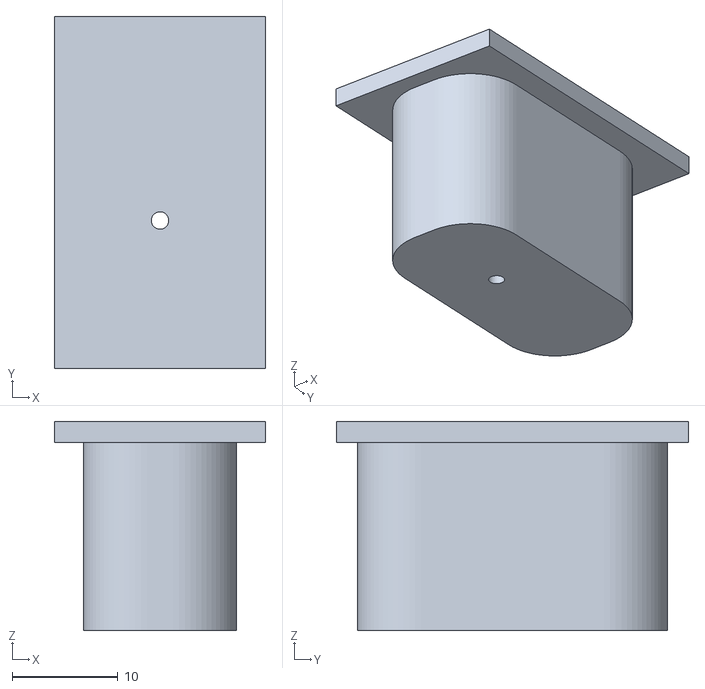
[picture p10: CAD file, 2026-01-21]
mechanical/Sensor Mount Jig.stl
20.0 x 33.3 x 19.8

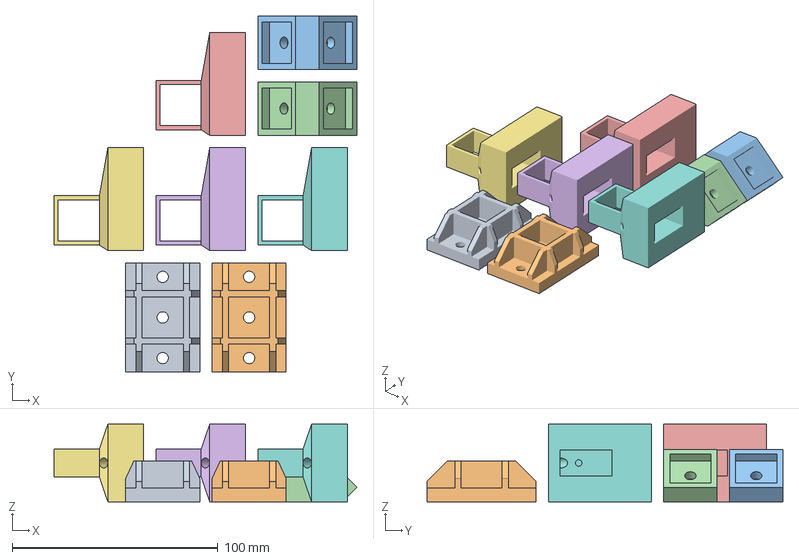
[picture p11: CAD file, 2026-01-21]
mechanical/EndGatePrusa.3mf
147.2 x 173.0 x 37.8 mm
Base.stl
RightAngle.stl
SensorCover.stl

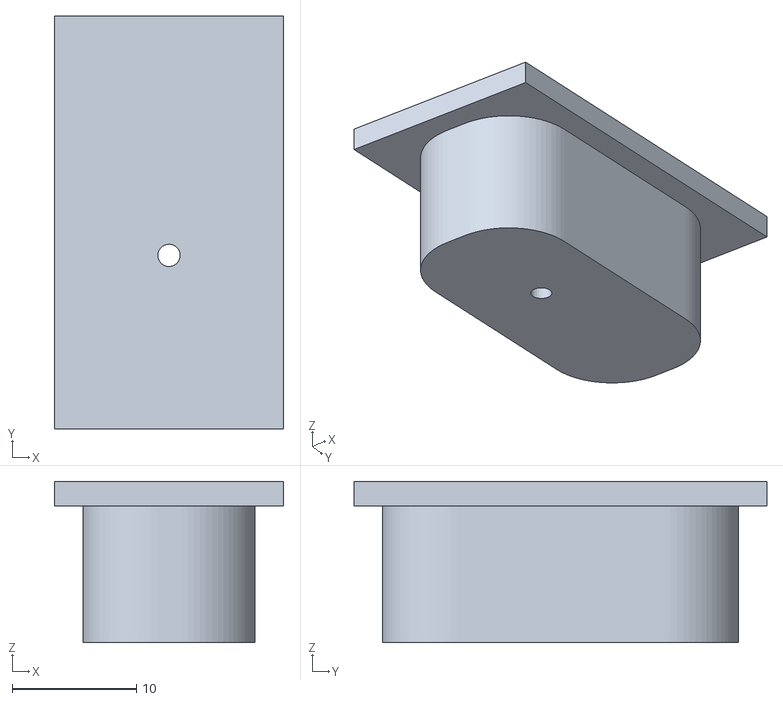
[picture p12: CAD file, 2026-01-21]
mechanical/SensorHoleJig.stl
18.5 x 33.3 x 13.0

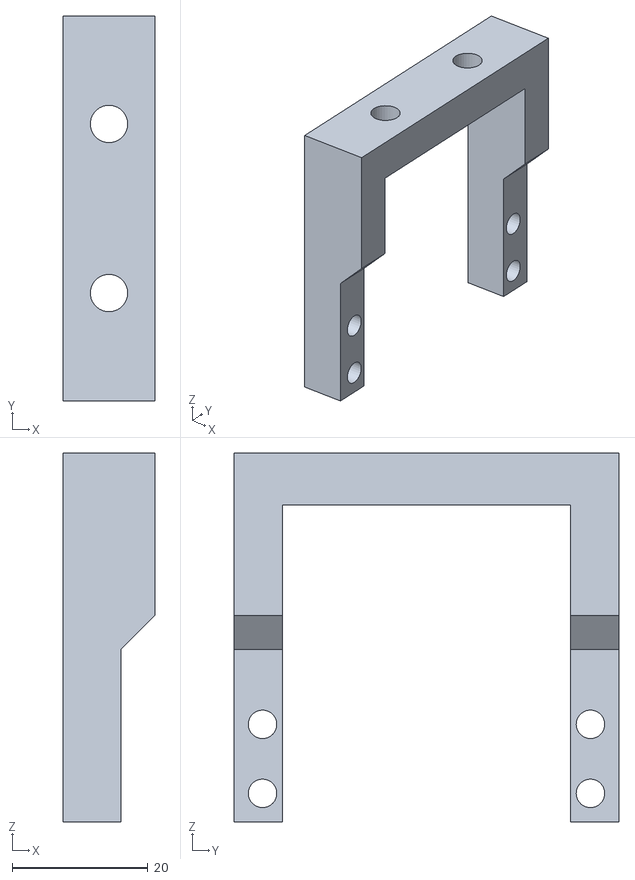
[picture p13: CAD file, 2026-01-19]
mechanical/ServoMount_v1.stl
13.5 x 56.7 x 54.3

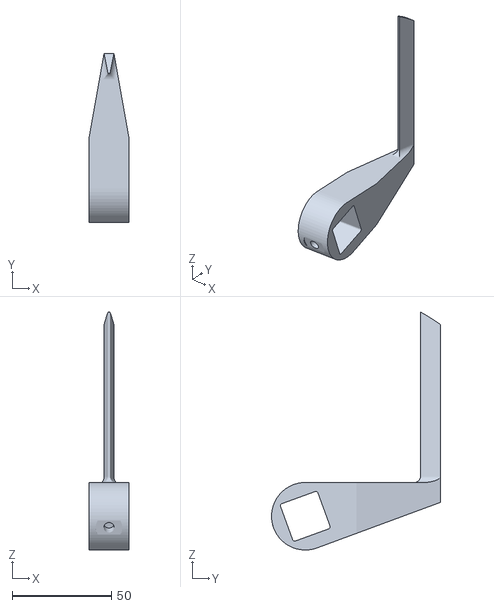
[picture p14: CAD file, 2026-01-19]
mechanical/Track_Gate_v1.stl
20.0 x 85.0 x 119.8

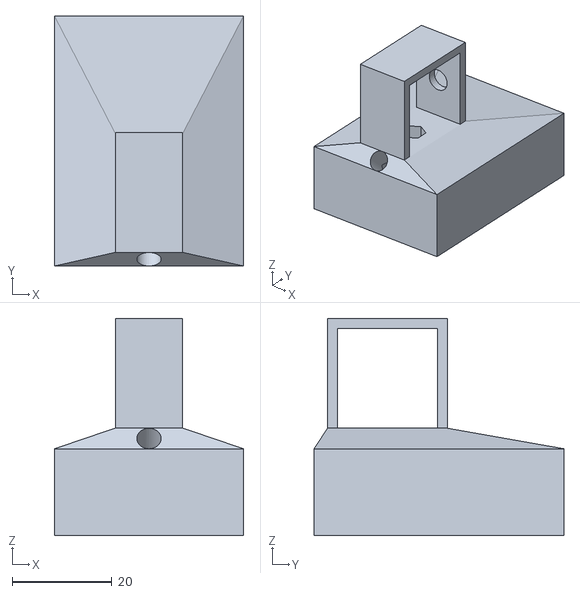
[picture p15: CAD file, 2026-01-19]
mechanical/SensorCover_v1.stl
37.8 x 50.0 x 43.5

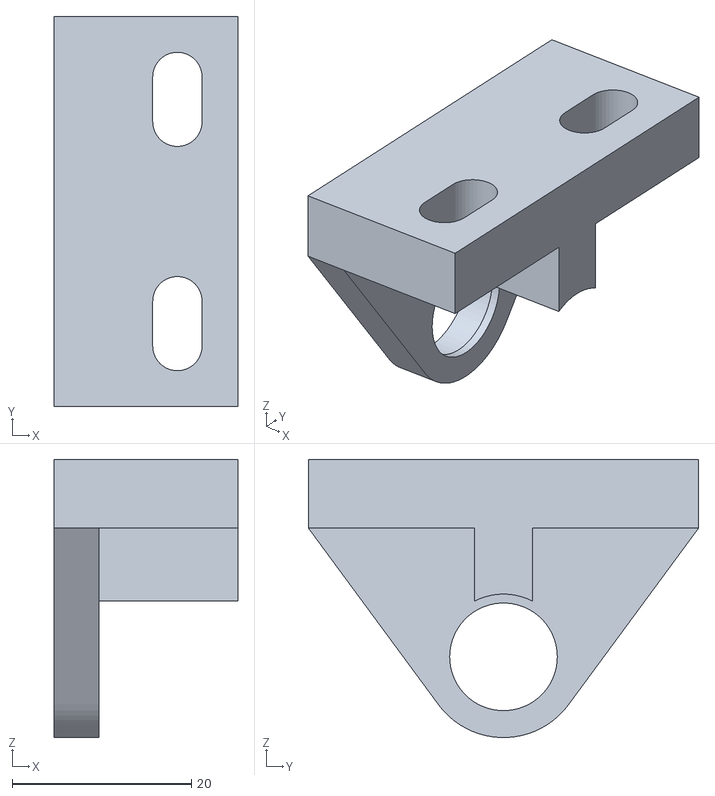
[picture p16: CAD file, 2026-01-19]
mechanical/Track_Pillow_v1.stl
20.5 x 43.5 x 31.0

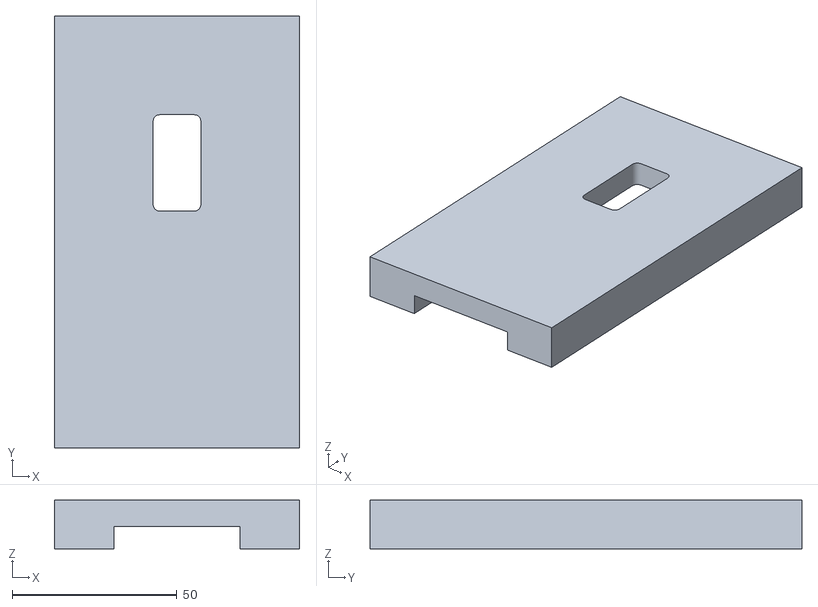
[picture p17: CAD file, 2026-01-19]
mechanical/SensorJig_v1.stl
74.5 x 131.3 x 14.7

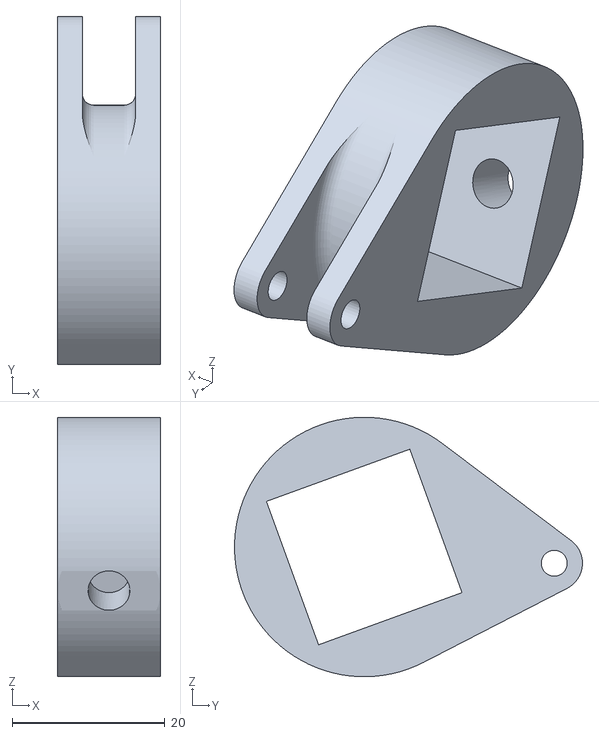
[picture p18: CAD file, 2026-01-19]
mechanical/Trigger_v1.stl
13.5 x 45.6 x 34.0

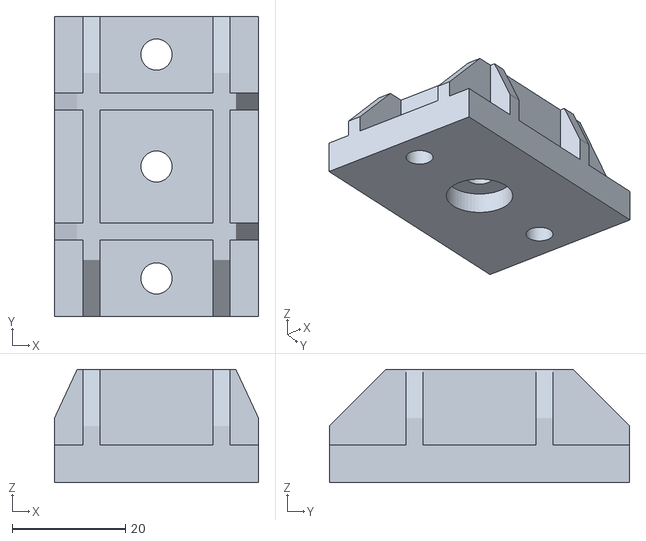
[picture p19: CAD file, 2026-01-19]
mechanical/Base_v1.stl
36.0 x 53.0 x 20.0

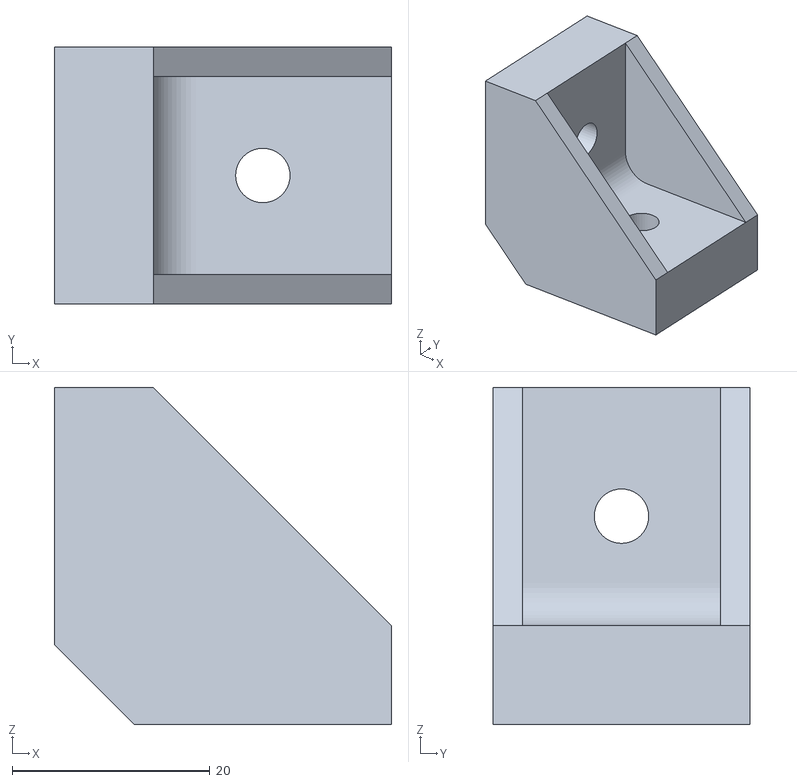
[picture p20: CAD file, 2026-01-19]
mechanical/RightAngle_v1.stl
34.1 x 26.0 x 34.1

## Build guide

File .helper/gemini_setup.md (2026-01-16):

# Gemini API Setup Guide

This guide walks you through setting up Google's Gemini API for the chat feature.

---

## 1. Get a Gemini API Key

### Option A: Google AI Studio (Recommended for Development)

1. Go to [Google AI Studio](https://aistudio.google.com/)
2. Sign in with your Google account
3. Click **"Get API Key"** in the top right
4. Click **"Create API Key"**
5. Choose an existing Google Cloud project or create a new one
6. Copy your API key
7. in your ./.env file, set 

### Option B: Google Cloud Console

1. Go to [Google Cloud Console](https://console.cloud.google.com/)
2. Create a new project or select an existing one
3. Navigate to **APIs & Services > Library**
4. Search for "Generative Language API" and enable it
5. Go to **APIs & Services > Credentials**
6. Click **"Create Credentials" > "API Key"**
7. Copy your API key

After copying your Gemini API key, add it to your project's `.env` file using the following variable name:

```
GEMINI_API_KEY=your_api_key_here
```

Make sure the `.env` file is located in your project root. This environment variable will be picked up by the backend automatically.

After updating the `.env` file, restart your development server or Docker containers to apply the change.

---

## 2. Billing Setup

### Free Tier Limits

Gemini offers a generous free tier:
- **Gemini 1.5 Flash**: 15 RPM, 1M TPM, 1,500 RPD
- **Gemini 1.5 Pro**: 2 RPM, 32K TPM, 50 RPD

(RPM = requests per minute, TPM = tokens per minute, RPD = requests per day)

### Enable Paid Billing (When Needed)

1. Go to [Google Cloud Console](https://console.cloud.google.com/)
2. Navigate to **Billing**
3. Click **"Link a billing account"** or create one
4. Add a payment method
5. Link the billing account to your project

### Pricing (as of Dec 2024)

| Model | Input (per 1M tokens) | Output (per 1M tokens) |
|---|---|---|
| Gemini 1.5 Flash | $0.075 | $0.30 |
| Gemini 1.5 Pro | $1.25 | $5.00 |

---

## 3. Add API Key to Project

Create a `.env` file in the project root (this file is gitignored):

```bash
GEMINI_API_KEY=your_api_key_here
```

The Docker Compose file will automatically load this environment variable.

---

## 4. Test Your Setup

Start the services:

```bash
./dev_build.sh
./dev_start.sh
```

Open the app at `http://localhost:3000` and click the chat button. Try asking:
- "Hello, who are you?"
- "What time is it?" (tests the tool calling)

---

## 5. Troubleshooting

### "API key not valid"
- Verify the key is correctly copied (no extra spaces)
- Make sure the Generative Language API is enabled
- Check if the key has any restrictions that block your requests

### "Quota exceeded"
- You've hit the free tier limits
- Wait for the rate limit to reset, or enable billing

### "Permission denied"
- The API might not be enabled for your project
- Go to Cloud Console > APIs & Services > Library > Enable "Generative Language API"

---

## 6. Security Notes

- **Never commit your API key** to version control
- Use environment variables for all secrets
- Rotate keys periodically in production
- Set up API key restrictions in Cloud Console for production use

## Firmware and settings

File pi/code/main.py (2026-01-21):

"""Pinewood Derby Track Controller API.

FastAPI server for controlling the race gate, reading sensors, and reporting results.
"""

import os
import json
import asyncio
from contextlib import asynccontextmanager
from fastapi import FastAPI, WebSocket, WebSocketDisconnect, HTTPException
from fastapi.middleware.cors import CORSMiddleware
from typing import List, Optional

from models import HeatSetup, HeatResult, GatePosition, HealthResponse, ServoCalibration, ServoTestRequest
from storage import HistoryManager
from hardware import MakeHardware
from discovery import registerService, unregisterService

# Configuration from environment
NUM_TRACKS = int(os.environ.get("NUM_TRACKS", 4))
API_PORT = int(os.environ.get("API_PORT", 8000))

# Global state
history_manager = HistoryManager()
hardware = None
active_websockets: List[WebSocket] = []


@asynccontextmanager
async def lifespan(app: FastAPI):
    """Startup and shutdown lifecycle management."""
    global hardware
    
    # Startup
    hardware = MakeHardware(NUM_TRACKS)
    await registerService(NUM_TRACKS, API_PORT)
    print(f"Track Controller API started with {NUM_TRACKS} tracks")
    
    yield
    
    # Shutdown
    await unregisterService()
    if hasattr(hardware, "cleanup"):
        hardware.cleanup()
    print("Track Controller API shut down")


app = FastAPI(
    title="Pinewood Derby Track Controller",
    description="API for controlling race gate and reading finish sensors",
    version="1.0.0",
    lifespan=lifespan,
)

# Enable CORS for web UI connections
app.add_middleware(
    CORSMiddleware,
    allow_origins=["*"],  # Allow all origins for local network
    allow_credentials=True,
    allow_methods=["*"],
    allow_headers=["*"],
)


# ----- Health & Discovery -----

@app.get("/health", response_model=HealthResponse)
def healthCheck():
    """Health check endpoint for service discovery."""
    return HealthResponse(
        status="healthy",
        num_tracks=hardware.num_tracks,
        is_gate_down=hardware.is_gate_down,
        current_heat_id=hardware.current_heat.heat_id if hardware.current_heat else None,
    )


# ----- Gate Control -----

@app.get("/gate")
def getGatePosition():
    """Get current gate position."""
    return {"is_gate_down": hardware.is_gate_down}


@app.post("/gate")
def setGatePosition(position: GatePosition):
    """Set gate position (up or down)."""
    hardware.setGate(position.is_down)
    return {"is_gate_down": hardware.is_gate_down}


# ----- Servo Calibration -----

@app.get("/servo/calibration")
def getServoCalibration():
    """Get current servo angle calibration."""
    return hardware.getCalibration()


@app.post("/servo/calibration")
def setServoCalibration(calibration: ServoCalibration):
    """
    Set servo angle calibration.
    
    Angles depend on your track geometry:
    - up_angle: Angle when gate holds cars (before race)
    - down_angle: Angle when gate releases cars (race start)
    """
    return hardware.setCalibration(calibration.up_angle, calibration.down_angle)


@app.post("/servo/test")
def testServoAngle(request: ServoTestRequest):
    """
    Move servo to a specific angle for testing/calibration.
    
    Use this to find the correct up_angle and down_angle for your track.
    Angle range: 0-180 degrees.
    """
    hardware.testServoAngle(request.angle)
    return {"angle": request.angle, "message": f"Servo moved to {request.angle}°"}


# ----- Race Execution -----

@app.post("/race/run")
async def runRace(setup: HeatSetup):
    """
    Start a race heat.
    
    Accepts heat_id and occupied_lanes, drops the gate, monitors sensors,
    and returns results. Results are also broadcast via WebSocket and persisted.
    
    If a heat is already in progress and a new heat is started (false start),
    the previous heat is cancelled and only the new heat's results are returned.
    """
    # Validate lanes
    for lane in setup.occupied_lanes:
        if lane < 1 or lane > hardware.num_tracks:
            raise HTTPException(
                status_code=400,
                detail=f"Invalid lane {lane}. Must be 1-{hardware.num_tracks}"
            )
    
    # Prepare and run the race
    hardware.prepareRace(setup)
    
    try:
        result = await hardware.runRace()
    except ValueError as e:
        # Heat was cancelled (false start) - return 409 Conflict
        if "cancelled" in str(e).lower():
            raise HTTPException(status_code=409, detail=str(e))
        raise
    
    # Persist result
    result_dict = result.model_dump(mode="json")
    history_manager.saveHeat(result_dict)
    
    # Broadcast to WebSocket clients
    await broadcastResult(result_dict)
    
    return result_dict


async def broadcastResult(result: dict):
    """Broadcast race result to all connected WebSocket clients."""
    message = json.dumps({"type": "race_result", "data": result})
    disconnected = []
    
    for ws in active_websockets:
        try:
            await ws.send_text(message)
        except Exception:
            disconnected.append(ws)
    
    # Clean up disconnected clients
    for ws in disconnected:
        active_websockets.remove(ws)


# ----- History / State Recovery -----

@app.get("/history")
def getHistory(limit: int = 100):
    """Get recent heat results for state recovery."""
    heats = history_manager.getHeats(limit)
    return {"heats": heats, "count": len(heats)}


@app.get("/history/{heat_id}")
def getHeatById(heat_id: str):
    """Get a specific heat result by ID."""
    heat = history_manager.getHeatById(heat_id)
    if not heat:
        raise HTTPException(status_code=404, detail=f"Heat {heat_id} not found")
    return heat


@app.get("/history/last")
def getLastHeat():
    """Get the most recent heat result."""
    heat = history_manager.getLastHeat()
    if not heat:
        raise HTTPException(status_code=404, detail="No heats recorded yet")
    return heat


# ----- WebSocket for Real-time Results -----

@app.websocket("/ws/results")
async def resultsWebsocket(websocket: WebSocket):
    """
    WebSocket endpoint for real-time race results.
    
    Clients connect here to receive race results as they complete.
    Also supports ping/pong for connection health.
    """
    await websocket.accept()
    active_websockets.append(websocket)
    print(f"WebSocket client connected. Total clients: {len(active_websockets)}")
    
    try:
        while True:
            # Handle incoming messages (ping/pong, etc.)
            data = await websocket.receive_text()
            
            try:
                message = json.loads(data)
                msg_type = message.get("type")
                
                if msg_type == "ping":
                    await websocket.send_text(json.dumps({"type": "pong"}))
                elif msg_type == "get_status":
                    status = hardware.getStatus()
                    await websocket.send_text(json.dumps({"type": "status", "data": status}))
                    
            except json.JSONDecodeError:
                await websocket.send_text(json.dumps({"type": "error", "message": "Invalid JSON"}))
                
    except WebSocketDisconnect:
        pass
    finally:
        if websocket in active_websockets:
            active_websockets.remove(websocket)
        print(f"WebSocket client disconnected. Total clients: {len(active_websockets)}")


# ----- WebSocket for Real-time Hardware Status -----

STATUS_STREAM_INTERVAL_MS = 50  # 20Hz updates

@app.websocket("/ws/status")
async def statusWebsocket(websocket: WebSocket):
    """
    WebSocket endpoint for real-time hardware status streaming.
    
    Streams sensor states and servo angle at 20Hz for live monitoring.
    Send {"type": "stop"} to pause streaming, {"type": "start"} to resume.
    """
    await websocket.accept()
    print("Hardware status WebSocket connected")
    
    is_streaming = True
    
    async def streamStatus():
        """Background task to stream hardware status."""
        nonlocal is_streaming
        while True:
            if is_streaming:
                try:
                    status = hardware.getHardwareStatus()
                    await websocket.send_text(json.dumps({
                        "type": "hardware_status",
                        "data": status
                    }))
                except Exception:
                    break
            await asyncio.sleep(STATUS_STREAM_INTERVAL_MS / 1000.0)
    
    # Start streaming in background
    stream_task = asyncio.create_task(streamStatus())
    
    try:
        while True:
            data = await websocket.receive_text()
            try:
                message = json.loads(data)
                msg_type = message.get("type")
                
                if msg_type == "stop":
                    is_streaming = False
                    await websocket.send_text(json.dumps({"type": "stopped"}))
                elif msg_type == "start":
                    is_streaming = True
                    await websocket.send_text(json.dumps({"type": "started"}))
                elif msg_type == "ping":
                    await websocket.send_text(json.dumps({"type": "pong"}))
                    
            except json.JSONDecodeError:
                pass
                
    except WebSocketDisconnect:
        pass
    finally:
        stream_task.cancel()
        print("Hardware status WebSocket disconnected")


# ----- Manual Entry Point (for direct python execution) -----

if __name__ == "__main__":
    import uvicorn
    uvicorn.run(app, host="0.0.0.0", port=API_PORT)

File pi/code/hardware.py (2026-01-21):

"""Hardware interface for PCA9685 servo driver, GPIO sensors.

Supports both real Raspberry Pi hardware and mock mode for local development.

Hardware:
- PCA9685 I2C PWM driver for servo control
- Hitec HS-5625MG servo for gate mechanism (digital, metal gear, high torque)
- DFRobot SEN0503 IR break-beam sensors for finish line

Race sequence:
1. Gate starts UP (servo at ~90°) - cars held at start
2. On "GO", gate moves DOWN (servo at ~0°) - cars released
3. START_TIME recorded when gate drops
4. Sensors detect cars crossing finish line
5. FINISH_TIME = time since gate drop
"""

import os
import json
import time
import asyncio
import random
from typing import List, Optional, Callable, Dict
from datetime import datetime
from models import HeatSetup, LaneResult, HeatResult

# Config file for persistent calibration
CONFIG_FILE = "servo_config.json"

# Default servo positions (can be overridden via API or env)
DEFAULT_SERVO_UP_ANGLE = int(os.environ.get("SERVO_UP_ANGLE", 60))
DEFAULT_SERVO_DOWN_ANGLE = int(os.environ.get("SERVO_DOWN_ANGLE", 0))
SERVO_CHANNEL = int(os.environ.get("SERVO_CHANNEL", 0))

# Timing
SENSOR_TIMEOUT_SEC = 30.0  # Max time to wait for all cars to finish
GATE_SETTLE_MS = 50        # Time to wait after gate drop before timing starts

# PCA9685 servo pulse widths (microseconds) - configurable for different servos
# HS-5625MG spec: 900-2100µs, neutral at 1500µs
SERVO_MIN_PULSE = int(os.environ.get("SERVO_MIN_PULSE", 900))   # 0 degrees
SERVO_MAX_PULSE = int(os.environ.get("SERVO_MAX_PULSE", 2100))  # max degrees
SERVO_ACTUATION_RANGE = int(os.environ.get("SERVO_ACTUATION_RANGE", 120))  # actual travel
SERVO_FREQ = 50         # 50Hz for standard servos


class HardwareInterface:
    """Base hardware interface - subclassed for real/mock implementations."""
    
    def __init__(self, num_tracks: int = 4):
        self.num_tracks = num_tracks
        self.is_gate_down = False
        self.current_heat: Optional[HeatSetup] = None
        self._result_callback: Optional[Callable] = None
        self.current_servo_angle: int = 0  # Track current angle for status
        self._heat_cancelled = False  # Flag to cancel in-progress heat
        
        # Load calibration from config file or use defaults
        self.servo_up_angle = DEFAULT_SERVO_UP_ANGLE
        self.servo_down_angle = DEFAULT_SERVO_DOWN_ANGLE
        self._loadCalibration()
    
    def _loadCalibration(self):
        """Load servo calibration from config file."""
        if os.path.exists(CONFIG_FILE):
            try:
                with open(CONFIG_FILE, "r") as f:
                    config = json.load(f)
                    self.servo_up_angle = config.get("up_angle", DEFAULT_SERVO_UP_ANGLE)
                    self.servo_down_angle = config.get("down_angle", DEFAULT_SERVO_DOWN_ANGLE)
                    print(f"Loaded calibration: UP={self.servo_up_angle}°, DOWN={self.servo_down_angle}°")
            except (json.JSONDecodeError, IOError) as e:
                print(f"Failed to load calibration: {e}, using defaults")
    
    def _saveCalibration(self):
        """Save servo calibration to config file."""
        config = {
            "up_angle": self.servo_up_angle,
            "down_angle": self.servo_down_angle,
        }
        with open(CONFIG_FILE, "w") as f:
            json.dump(config, f, indent=2)
        print(f"Saved calibration: UP={self.servo_up_angle}°, DOWN={self.servo_down_angle}°")
    
    def setResultCallback(self, callback: Callable):
        """Set callback function to be called when race results are ready."""
        self._result_callback = callback
    
    def setGate(self, is_down: bool):
        """Set gate position (up=holding, down=released)."""
        raise NotImplementedError
    
    def raiseGate(self):
        """Raise gate to hold cars (UP position)."""
        self.setGate(is_down=False)
    
    def dropGate(self):
        """Drop gate to release cars (DOWN position)."""
        self.setGate(is_down=True)
    
    def testServoAngle(self, angle: int):
        """Move servo to a specific angle for calibration testing."""
        raise NotImplementedError
    
    def getCalibration(self) -> dict:
        """Get current servo calibration."""
        return {
            "up_angle": self.servo_up_angle,
            "down_angle": self.servo_down_angle,
        }
    
    def setCalibration(self, up_angle: int, down_angle: int):
        """Set and persist servo calibration."""
        max_angle = int(os.environ.get("SERVO_ACTUATION_RANGE", 120))
        self.servo_up_angle = max(0, min(max_angle, up_angle))
        self.servo_down_angle = max(0, min(max_angle, down_angle))
        self._saveCalibration()
        return self.getCalibration()
    
    def prepareRace(self, setup: HeatSetup):
        """Prepare for a race with given configuration."""
        # Cancel any in-progress heat (false start handling)
        self._heat_cancelled = True
        self.current_heat = setup
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

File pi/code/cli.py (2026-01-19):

#!/usr/bin/env python3
"""CLI tool for the Pi Track Controller API.

Usage:
    # Start server (uses real hardware on Pi, or --mock for local dev)
    python cli.py serve
    python cli.py serve --mock
    
    # In another terminal, run commands:
    python cli.py health
    python cli.py gate up|down
    python cli.py race <heat_id> <lanes>   # e.g., race heat-1 1,2,3,4
    python cli.py servo test <angle>
    python cli.py servo calibrate <up> <down>
    python cli.py history
"""

import argparse
import sys
import os
import json
import httpx

DEFAULT_HOST = "http://localhost:8000"


def getClient():
    """Get HTTP client with base URL from env or default."""
    base_url = os.environ.get("PI_API_URL", DEFAULT_HOST)
    return httpx.Client(base_url=base_url, timeout=60.0)


def cmdServe(args):
    """Start the API server."""
    if args.mock:
        os.environ["MOCK_HARDWARE"] = "1"
    os.environ["NUM_TRACKS"] = str(args.tracks)
    os.environ["API_PORT"] = str(args.port)
    
    import uvicorn
    from main import app
    
    mode = "MOCK" if args.mock else "REAL HARDWARE"
    print(f"\n🏎️  Starting Pi Track Controller ({mode})")
    print(f"   Tracks: {args.tracks}")
    print(f"   Port: {args.port}")
    print(f"   URL: http://localhost:{args.port}\n")
    
    uvicorn.run(app, host="0.0.0.0", port=args.port)


def cmdHealth(args):
    """Check API health."""
    with getClient() as client:
        r = client.get("/health")
        r.raise_for_status()
        data = r.json()
        print(json.dumps(data, indent=2))


def cmdGate(args):
    """Get or set gate position."""
    with getClient() as client:
        if args.position:
            is_down = args.position.lower() == "down"
            r = client.post("/gate", json={"is_down": is_down})
        else:
            r = client.get("/gate")
        r.raise_for_status()
        data = r.json()
        state = "DOWN" if data["is_gate_down"] else "UP"
        print(f"Gate: {state}")


def cmdRace(args):
    """Run a race heat."""
    lanes = [int(x.strip()) for x in args.lanes.split(",")]
    
    with getClient() as client:
        print(f"🏁 Starting race: heat={args.heat_id}, lanes={lanes}")
        r = client.post("/race/run", json={
            "heat_id": args.heat_id,
            "occupied_lanes": lanes
        })
        r.raise_for_status()
        result = r.json()
        
        print(f"\n📊 Results for {result['heat_id']}:")
        print("-" * 40)
        
        for lane in result["lane_results"]:
            if lane["finish_time_ms"] is not None:
                print(f"  Lane {lane['lane_number']}: {lane['finish_time_ms']:.2f}ms (#{lane['place']})")
            elif lane["is_dnf"]:
                print(f"  Lane {lane['lane_number']}: DNF")
            else:
                print(f"  Lane {lane['lane_number']}: --")
        print()


def cmdServo(args):
    """Servo test and calibration commands."""
    with getClient() as client:
        if args.servo_cmd == "test":
            r = client.post("/servo/test", json={"angle": args.angle})
            r.raise_for_status()
            print(f"Servo moved to {args.angle}°")
        
        elif args.servo_cmd == "calibrate":
            r = client.post("/servo/calibration", json={
                "up_angle": args.up_angle,
                "down_angle": args.down_angle
            })
            r.raise_for_status()
            data = r.json()
            print(f"Calibration set: UP={data['up_angle']}°, DOWN={data['down_angle']}°")
        
        elif args.servo_cmd == "status":
            r = client.get("/servo/calibration")
            r.raise_for_status()
            data = r.json()
            print(f"Calibration: UP={data['up_angle']}°, DOWN={data['down_angle']}°")


def cmdHistory(args):
    """Get race history."""
    with getClient() as client:
        r = client.get("/history", params={"limit": args.limit})
        r.raise_for_status()
        data = r.json()
        
        if not data["heats"]:
            print("No race history")
            return
        
        print(f"Last {len(data['heats'])} heats:")
        for heat in data["heats"]:
            print(f"  {heat['heat_id']} @ {heat['started_at']}")


def main():
    parser = argparse.ArgumentParser(
        description="Pi Track Controller CLI",
        formatter_class=argparse.RawDescriptionHelpFormatter,
        epilog=__doc__
    )
    subparsers = parser.add_subparsers(dest="command", required=True)
    
    # serve
    p_serve = subparsers.add_parser("serve", help="Start API server")
    p_serve.add_argument("-p", "--port", type=int, default=8000, help="Port (default: 8000)")
    p_serve.add_argument("-t", "--tracks", type=int, default=4, help="Number of tracks (default: 4)")
    p_serve.add_argument("-m", "--mock", action="store_true", help="Use mock hardware (for local dev)")
    p_serve.set_defaults(func=cmdServe)
    
    # health
    p_health = subparsers.add_parser("health", help="Check API health")
    p_health.set_defaults(func=cmdHealth)
    
    # gate
    p_gate = subparsers.add_parser("gate", help="Get/set gate position")
    p_gate.add_argument("position", nargs="?", choices=["up", "down"], help="Set position")
    p_gate.set_defaults(func=cmdGate)
    
    # race
    p_race = subparsers.add_parser("race", help="Run a race heat")
    p_race.add_argument("heat_id", help="Heat identifier")
    p_race.add_argument("lanes", help="Comma-separated lane numbers (e.g., 1,2,3,4)")
    p_race.set_defaults(func=cmdRace)
    
    # servo
    p_servo = subparsers.add_parser("servo", help="Servo commands")
    servo_sub = p_servo.add_subparsers(dest="servo_cmd", required=True)
    
    p_servo_test = servo_sub.add_parser("test", help="Test servo at angle")
    p_servo_test.add_argument("angle", type=int, help="Angle (0-180)")
    
    p_servo_cal = servo_sub.add_parser("calibrate", help="Set calibration")
    p_servo_cal.add_argument("up_angle", type=int, help="UP angle (holding)")
    p_servo_cal.add_argument("down_angle", type=int, help="DOWN angle (released)")
    
    servo_sub.add_parser("status", help="Get calibration")
    
    p_servo.set_defaults(func=cmdServo)
    
    # history
    p_history = subparsers.add_parser("history", help="Get race history")
    p_history.add_argument("-l", "--limit", type=int, default=10, help="Max heats (default: 10)")
    p_history.set_defaults(func=cmdHistory)
    
    args = parser.parse_args()
    
    try:
        args.func(args)
    except httpx.ConnectError:
        print(f"❌ Cannot connect to API. Is the server running?")
        print(f"   Start with: python cli.py serve")
        sys.exit(1)
    except httpx.HTTPStatusError as e:
        print(f"❌ API error: {e.response.status_code}")
        print(f"   {e.response.text}")
        sys.exit(1)


if __name__ == "__main__":
    main()

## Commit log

2026-01-17 Add Raspberry Pi track controller API
    - FastAPI server for gate control and sensor reading
    - Mock hardware mode for local development
    - JSON file storage for 1000 heat history
    - Zeroconf/mDNS for network discovery
    - One-command SD card preparation script
    - systemd service for auto-start and crash recovery
    [discovery.py, hardware.py, main.py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]
2026-01-17 Add hardware documentation and update for PCA9685 servo driver
    - HARDWARE.md with wiring diagrams for PCA9685, HS-422, SEN0503
    - Update hardware.py to use I2C PCA9685 servo driver
    - Gate UP=holding (90°), DOWN=released (0°) - timing starts on drop
    - High-precision timing with time.monotonic_ns()
    - Install scripts now include I2C tools and Adafruit libraries
    - env.template for WiFi configuration
2026-01-19 project cleanup
    [Base_v1.stl, RightAngle_v1.stl, SensorCover_v1.stl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]
2026-01-21 add real-time Pi WebSocket connection for hardware status
    - Add /ws/status WebSocket endpoint to Pi for streaming sensor/servo state at 20Hz
    - Add CORS middleware to Pi API for browser connections
    - Create usePiWebSocket hook for real-time hardware status
    - Update setup page with live sensor display and servo angle
    - Add pi_url to settings for configuring Pi connection
    - Update deploy script to auto-restart service after deploy
    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
2026-01-21 add stale connection detection for Pi WebSocket
    Monitors for missing data - if no message received for 2 seconds
    (Pi streams at 20Hz), forces reconnect. Detects Pi going offline
    within ~2-3 seconds instead of waiting for TCP timeout.
2026-01-21 debug works
    [EndGatePrusa.3mf, PiMount.stl, PiMount_v2.stl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]
2026-01-21 add race state machine with false start handling
    - Pi: add _heat_cancelled flag to cancel in-progress heats when
    prepareRace is called again (handles false starts gracefully)
    - Pi: return 409 Conflict when heat is cancelled mid-race
    - API: add clear_heat_times and raise_gate actions
    - API: trigger_gate now calls Pi /race/run with occupied_lanes
    - Heats UI: refactor to state machine (idle → ready → racing)
    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
